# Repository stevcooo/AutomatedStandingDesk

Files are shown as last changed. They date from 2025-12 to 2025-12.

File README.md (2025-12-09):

Here is my story.
Like many of us who work from home, after a while, you start to think that a standing desk would be a nice addition to your home setup. And yes, it is, but it’s cool and nice only in the beginning, at least for me. Then I stopped using it, and it became a regular desk, which from time to time served as an expensive lift toy for my daughter… but it looks like she lost interest too.

Unfortunately, the model I got has controls to adjust the height (up and down) and four positions that can be memorized. You find a nice height that works for you, you memorize it, and if you move it up and down later, you can easily return to your desired state. Kind of like a digital radio system.

Turns out, not using your standing desk after a while is a common thing. I’ve checked with many of my friends and colleagues. Okay, let’s automate it. How hard can it be?

We need something that will press the button. We have two options here: you can buy a [Fingerbot](https://www.aliexpress.com/item/1005005923713363.html) for $40 and skip reading the whole saga below, or you can keep reading and spend a few days on it—it's more fun, I can guarantee.

If you’ve made it this far, I assume you’re either curious or you have some extra time to spend. Let’s go!

> _There is a links section in the end of the document where I listed links for each of the parts that I mention in the text_

A servo motor can do the trick, even the cheapest one. Someone needs to give the signal to the motor to start rotating, press the button, and then release it. Okay, any Arduino board will do the trick.

Next, you need to be able to set a time when you want your desk to move to a standing position. For that, you need something that will keep the date/time running and inform the Arduino. Turns out there are tons of components that can do that. I know, ChatGPT told me! I bought a cheap one, the `DS3231`. It can even be attached to a battery, so it won’t lose time if you unplug the power for some reason. Cool! Turns out the same component has an integrated alarm too, so you can set it as well. Perfect.

Imagine you put everything together. You still need a way to attach the motor to the desk controller, drilling or gluing it isn’t an option. After spending 30 minutes measuring and attempting four failed prints, my 3D printer finally managed to produce a perfect piece. Awesome!

[Check it out](https://github.com/stevcooo/AutomatedStandingDesk/blob/main/3DModel/MG50S_servo_mount_to_Strong_standing_desk_controller.stl)

Let’s bring everything together!
I’ve got an ESP32 with WiFi and a display, an MG90S micro servo motor, and a DS3231 for the clock. The good thing about the ESP32 with WiFi is that it can host a network where you can access the Arduino from your phone and set some values, like the date and time, and most importantly, the alarm for when you want the trigger to happen.

I won’t bore you with details here; the whole code is in the repository, where you can go through it or even edit it yourself to tweak it. I’m sure you can make this better!

All the wiring details and technical descriptions are below if you want to go deeper. You can also see the 3D design and edit it to fit your desk or motor.

Now, I set the alarm on the `DS3231` component via the Web interface and my desk is moving to standing position every day, 2minutes before the morning meeting. Yay!

Here is a video how it works in action (you may need to click on the picture to open the YouTube video):
<a href="https://www.youtube.com/watch?v=pzgJn2215ew" target="_blank">
Watch the video
</a>

# ESP32 Daily Alarm Clock + Servo Button Presser

An ESP32-based clock using a DS3231 RTC and SSD1306 OLED display.  
It hosts a Wi‑Fi Access Point with a small web UI to:

- Set date/time on the RTC
- Configure a **daily alarm**
- Disable the alarm
- View current RTC time

When the alarm fires, the DS3231 triggers an interrupt on the ESP32, and the ESP32 drives a servo that “presses a button” (or any physical switch) via a simple press‑and‑return routine.

---

## Features

- **Hardware timekeeping** via DS3231 RTC (battery‑backed)
- **OLED time display** updated once per second
- **Daily alarm** using DS3231 Alarm1 interrupt pin
- **Servo‑triggered action** on alarm
- **Wi‑Fi AP + Web UI** for easy setup without needing a router

---

## Pin Mapping (from the code)

These pins are defined in the sketch:

| Module / Signal | ESP32 Pin | Notes |
| --- | ---: | --- |
| **Servo signal** | GPIO **18** | `servoPin = 18` |
| **RTC Alarm INT/SQW** | GPIO **27** | `ALARM_INT_PIN = 27`, input pullup, falling edge ISR |
| **I2C SDA** | GPIO **21** | `Wire.begin(21,22)` |
| **I2C SCL** | GPIO **22** | `Wire.begin(21,22)` |
| **OLED I2C addr** | 0x3C | `OLED_ADDR = 0x3C` |
| **Wi‑Fi AP SSID** | `ESP32-Clock` | password `12345678` |

RTC and OLED **share the same I2C bus**.

---

## Wiring Table

### 1) DS3231 RTC

<p align="center" width="100%">
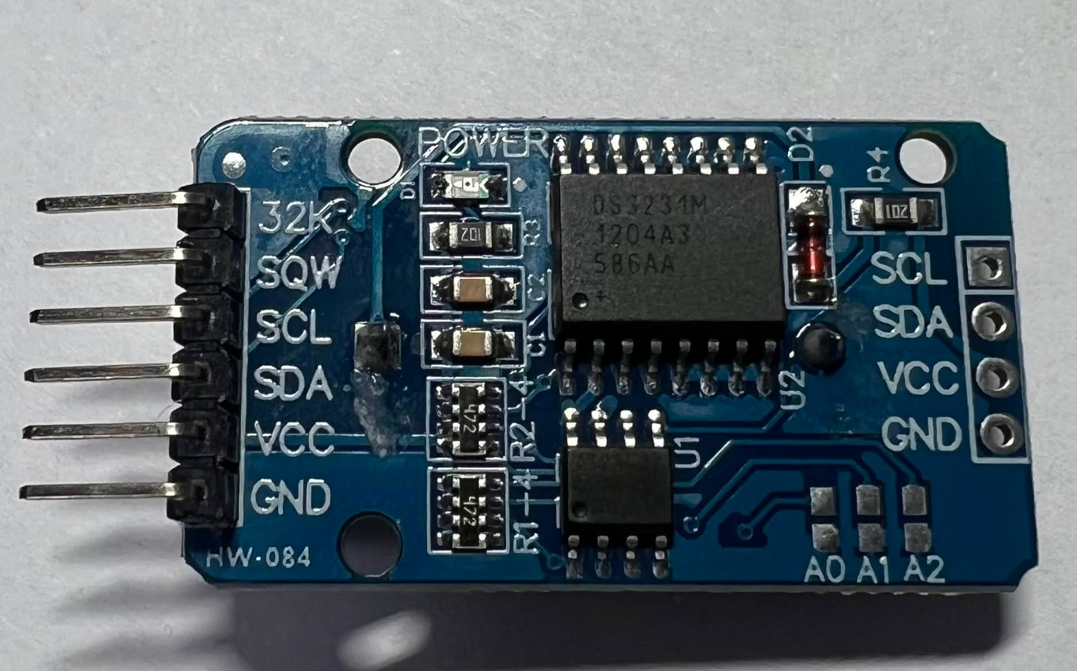
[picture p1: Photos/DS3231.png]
   
</p>

| DS3231 Pin | Connect to ESP32 | Notes |
| --- | --- | --- |
| VCC | 3V3 | DS3231 modules are usually 3.3–5V tolerant; 3V3 is safest |
| GND | GND | common ground |
| SDA | GPIO 21 | I2C data |
| SCL | GPIO 22 | I2C clock |
| INT/SQW | GPIO 27 | alarm interrupt output |

### 2) Servo (standard 3‑wire)

<p align="center" width="100%">
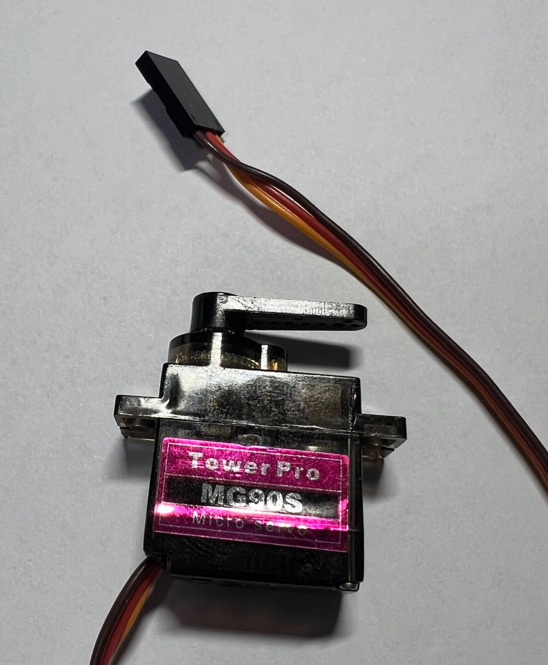
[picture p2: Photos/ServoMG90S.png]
   
</p>

| Servo Wire | Connect to ESP32 | Notes |
| --- | --- | --- |
| Signal (usually yellow/orange) | GPIO 18 | PWM via LEDC |
| V+ (usually red) | **5V external** recommended | ESP32 5V pin _might_ work for micro servos but can brown out |
| GND (usually brown/black) | GND | must share ground with ESP32 |

> Important: servo power spikes can reset the ESP32. Use a separate 5V supply if possible, and **tie grounds together**.

---

## Graphical Wiring Diagram (Fritzing‑style, text)

Legend:

- `==` I2C bus line (shared)
- `---` single signal line
- `+++` power rail
- `⏚` ground rail

```
                    ┌──────────────────────────────┐
                    │             ESP32            │
                    │                              │
   3V3  +++─────────┤ 3V3                      GND ├────────⏚
                    │                              │
   SDA  ==──────────┤ GPIO21 (SDA)                 │
   SCL  ==──────────┤ GPIO22 (SCL)                 │
 Alarm ---──────────┤ GPIO27                       │
 Servo ---──────────┤ GPIO18 (PWM)                 │
                    └──────────────┬───────────────┘
                                   │
                   ┌───────────────┼
                   │               │
                   │               │
        I2C BUS ===│=== SDA/SCL ===│
                   │               │
                   ▼               ▼

      ┌─────────────────┐   ┌─────────────────┐
      │    DS3231 RTC   │   │      SERVO      │
      │                 │   │                 │
      │ VCC  +++────────┼───│ V+   +++ 5V EXT │
      │ GND  ⏚──────────│───│ GND  ⏚───────── ┼───⏚
      │ SDA  ==─────────┼───│ SIG  --- GPIO18 │
      │ SCL  ==─────────┼───└─────────────────┘
      │ INT  --- GPIO27 │
      └─────────────────┘
```

Power rails:

- **3V3 rail** feeds **RTC VCC** and **OLED VCC**
- **5V external rail** feeds **Servo V+**
- **All grounds join at ESP32 GND**

---

## How It Works

1. **RTC time** is read once per second and drawn on the OLED.
2. **Daily alarm** is set using DS3231 Alarm1 in “match hour/min/sec” mode.
3. When alarm time matches, DS3231 pulls **INT/SQW low**, triggering ESP32 ISR.
4. Main loop sees `alarmFiredFlag` and:
   - clears RTC alarm flag
   - runs `pressAndReturn()` to actuate the servo

Servo routine (timings from code):

- Move “back” for `travelMs`
- Hold for `holdMs`
- Move “press” for `travelMs`
- Stop and settle

You can tune:

```cpp
int pressUs  = 1150;
int backUs   = 1890;
int travelMs = 60;
int holdMs   = 15000;
int settleMs = 200;
```

---

## Setup & Usage

### 1) Flash the ESP32

<p align="center" width="100%">
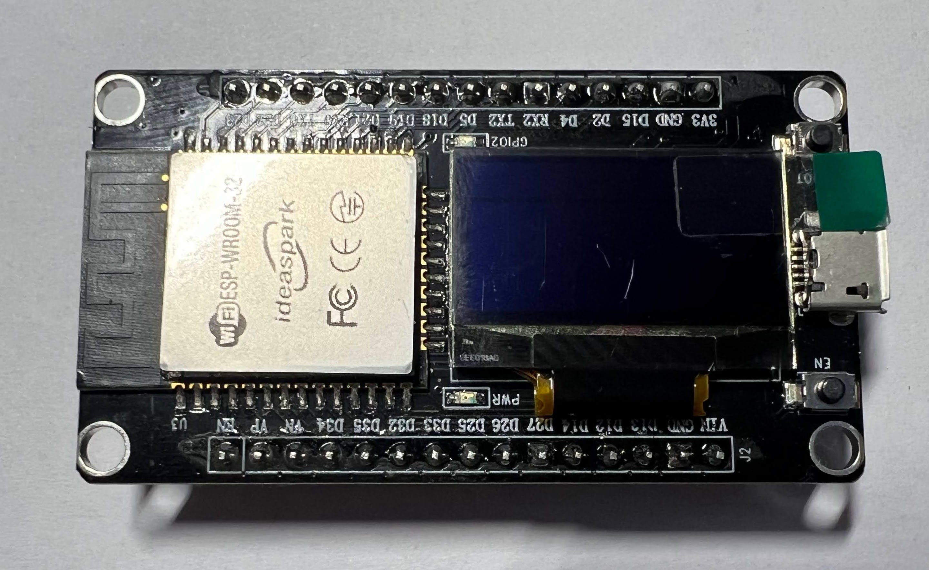
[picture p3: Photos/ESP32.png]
   
</p>

Open in Arduino IDE (ESP32 core installed), select your board, then upload.

Here is my configuration for the board:

<p align="center" width="100%">
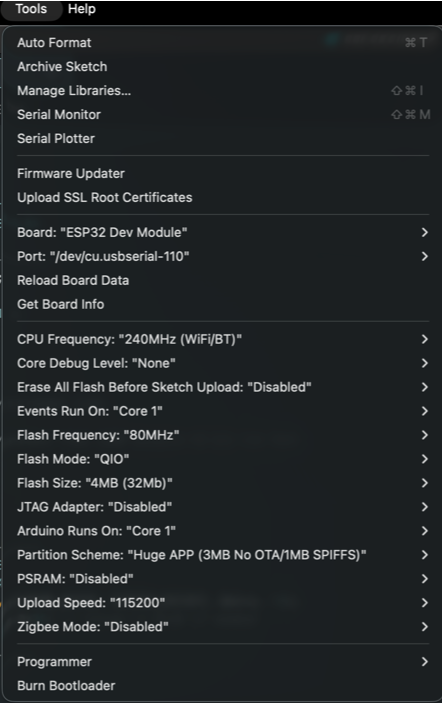
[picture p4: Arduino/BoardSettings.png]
   
</p>

### 2) Connect to AP

On your phone/laptop:

- SSID: **ESP32-Clock**
- Password: **12345678**

### 3) Open Web UI

Navigate to:

- `http://192.168.4.1/`

You’ll see:

- **Set Date & Time**
- **Daily Alarm**
- **Disable Alarm**
- **Status link**

<p align="center" width="100%">
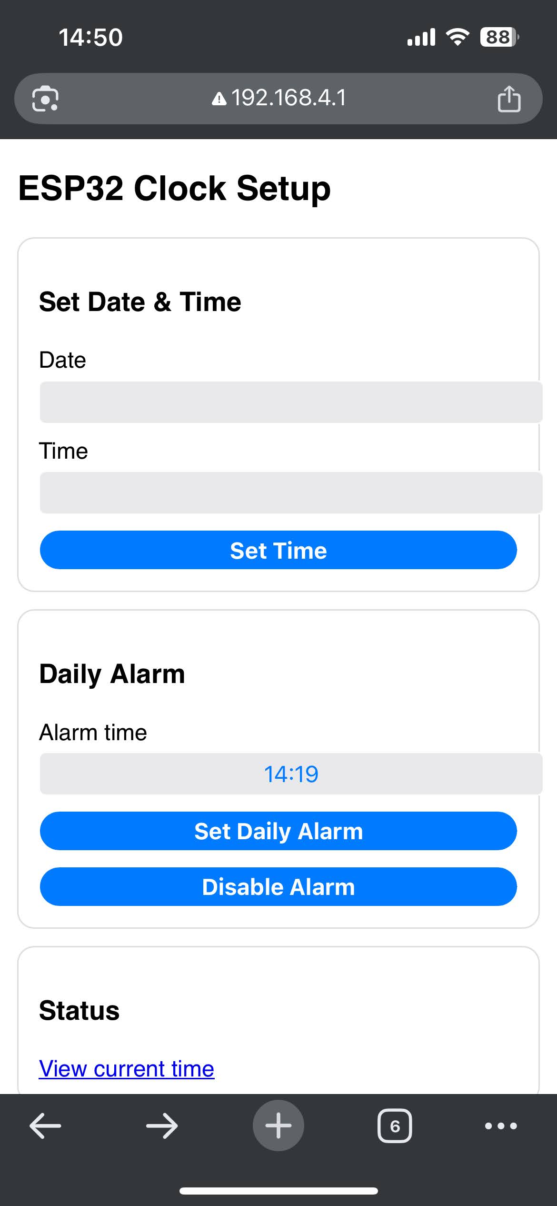
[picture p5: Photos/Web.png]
   
</p>

### 4) Status Endpoint

`http://192.168.4.1/status` returns plain text:

```
YYYY-MM-DD HH:MM:SS
```

---

## Notes / Tips

- If your OLED doesn’t show anything, your module may be at **0x3D**; change:
  ```cpp
  const uint8_t OLED_ADDR = 0x3D;
  ```
- DS3231 INT pin is **open‑drain active‑low**, so `INPUT_PULLUP` is correct.
- If the alarm fires immediately after setting:
  - you likely left a stale alarm flag; the code clears alarms on set and on fire.
- Use a proper 5V servo supply for reliability.

---

## Possible Extensions

- Add a “test servo” button to the UI
- Add multiple alarms (Alarm2 or software scheduling)
- Sync time from NTP when connected to the internet
- Show alarm status / next alarm time on OLED
- Draw PCB board where you can put the components directly, something like motherboard

## Links

- [3D model STL](/3DModel/MG50S_servo_mount_to_Strong_standing_desk_controller.stl)
- [3D model online](https://www.tinkercad.com/things/0ZuuW3NavJP-fantabulous-amur-lahdi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)
- [ESP32 Development Board with 0.96 Inch OLED Display](https://www.aliexpress.com/item/1005006269242344.html?spm=a2g0o.order_list.order_list_main.90.ea711802LYOdQG)
- [Micro Servo MG90S](https://www.aliexpress.com/item/32945021008.html)
- [DS3231](https://www.aliexpress.com/item/1005006996032750.html)
- [PCB Board Protoboard For Arduino](https://www.aliexpress.com/item/32981958921.html)

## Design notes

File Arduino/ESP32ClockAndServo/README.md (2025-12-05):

# ESP32 DS3231 Clock + OLED + Daily Alarm (Wi-Fi AP Web UI)

This project runs on an **ESP32** connected to a **DS3231 RTC** and a **128×64 SSD1306 OLED**.  
The ESP32 creates a Wi-Fi Access Point, hosts a small web UI, and lets you:

- Set **date & time** on the DS3231  
- Set a **daily alarm** (HH:MM or HH:MM:SS)  
- Display current time on an OLED  
- Trigger an interrupt when the alarm fires (for your custom action)

---

## Features

- **Self-hosted AP + Web UI** (no router required)  
- **RTC-backed timekeeping** (DS3231 battery keeps time when ESP32 is off)  
- **Daily repeating alarm** using DS3231 Alarm1 + INT pin  
- **OLED live clock** update every second  
- Alarm time parser accepts both `HH:MM` and `HH:MM:SS`

---

## Hardware

### Required
- ESP32 dev board
- DS3231 RTC module
- SSD1306 128×64 I2C OLED (0x3C typical)
- Jumper wires
- (Optional) DS3231 coin cell battery (CR2032)

---

## Wiring / Schematics

### I2C Bus Connections

Both the DS3231 and OLED share the same I2C bus:

| ESP32 Pin | DS3231 Pin | OLED Pin | Notes |
|---:|---|---|---|
| 3V3 | VCC | VCC | Use 3.3V unless your modules explicitly require 5V |
| GND | GND | GND | Common ground |
| GPIO21 | SDA | SDA | I2C data |
| GPIO22 | SCL | SCL | I2C clock |

### Alarm Interrupt Connection

| ESP32 Pin | DS3231 Pin | Notes |
|---:|---|---|
| GPIO27 | SQW / INT  | Alarm output, active LOW. ESP32 uses INPUT_PULLUP. |

### ASCII Schematic

```
                +------------------+
                |      ESP32       |
                |                  |
3V3  ---------- | 3V3          GND | ---------- GND
GND  ---------- | GND              |
SDA (GPIO21) -- | GPIO21 (SDA)     |
SCL (GPIO22) -- | GPIO22 (SCL)     |
INT (GPIO27) -- | GPIO27           |
                +------------------+
                     |   |   |
                     |   |   |
                     |   |   +-------------------+
                     |   |                       |
                     |   +-----------+           |
                     |               |           |
          +----------------+   +----------------------+
          |    DS3231      |   |   SSD1306 OLED       |
          |                |   |                      |
          | VCC   GND SDA  |   | VCC  GND  SDA  SCL   |
          |  |     |   |   |   |  |    |    |    |    |
          +--|-----|---|---+   +--|----|----|----|----+
             |     |   |          |    |    |    |
             |     |   +----------+    |    |    |
             |     +-------------------+    |    |
             +------------------------------+    |
                                    +------------+
```

**Notes**
- Most DS3231 + SSD1306 I2C modules work fine at 3.3V. If yours is 5V-only, use 5V VCC but ensure SDA/SCL have pullups compatible with ESP32 (usually still OK because modules use open-drain).  
- INT/SQW on DS3231 is **open-drain active-low**, so ESP32 internal pull-up is correct.

---

## How It Works

1. ESP32 boots and initializes I2C, OLED, and RTC.
2. It disables and clears any old alarms on the DS3231.
3. ESP32 starts a **Wi-Fi Access Point**:
   - SSID: `ESP32-Clock`
   - Password: `12345678`
4. A web server runs at port 80 with:
   - `/` a setup UI
   - `/setTime` to set RTC time
   - `/setAlarm` to set daily alarm
   - `/alarmOff` to disable alarm
   - `/status` to read current time
5. When Alarm1 fires, DS3231 pulls INT low → ESP32 interrupt sets a flag → loop clears alarm and runs your action.

---

## Web Endpoints

### Set Date & Time
**GET /setTime?d=YYYY-MM-DD&t=HH:MM:SS**

Example:
```
/setTime?d=2025-12-01&t=14:30:00
```

### Set Daily Alarm
**GET /setAlarm?a=HH:MM** or **HH:MM:SS**

Examples:
```
/setAlarm?a=07:00
/setAlarm?a=07:00:30
```

If seconds are missing, they default to `00`.

### Disable Alarm
**GET /alarmOff**

### Read Current Time
**GET /status**

Returns:
```
YYYY-MM-DD HH:MM:SS
```

---

## Finding the AP IP Address

When ESP32 creates the AP, it prints the IP to Serial:

```cpp
Serial.print("AP IP: ");
Serial.println(WiFi.softAPIP());
```

### Default IP
ESP32 SoftAP commonly uses:
```
192.168.4.1
```
…but you should **trust the Serial output**.

### If the IP doesn’t match / you can’t connect
1. **Open Serial Monitor** at `115200 baud`
2. Reset the ESP32
3. Look for:
   ```
   AP IP: x.x.x.x
   ```
4. Use that IP in your browser:
   ```
   http://x.x.x.x/
   ```

If you still can’t see the network:
- Ensure ESP32 is in AP mode (`WiFi.mode(WIFI_AP)`)
- Confirm SSID/password in code
- Try forgetting the network on your device and reconnecting

---

## Customizing Alarm Action

In `loop()`:

```cpp
if (alarmFiredFlag) {
  alarmFiredFlag = false;
  rtc.clearAlarm(1);
  // Alarm action here
  Serial.println("ALARM!");
}
```

Replace the comment with anything you want (servo, relay, buzzer, etc).

---

## Troubleshooting

### OLED does not display
- Check OLED I2C address (0x3C vs 0x3D).
- Use an I2C scanner if unsure.
- Confirm SDA/SCL wiring and shared ground.

### Alarm never fires
- Ensure SQW/INT pin is wired to GPIO27.
- Ensure `rtc.writeSqwPinMode(DS3231_OFF)` is called.
- Ensure you cleared old alarms before setting new ones.

### “Bad alarm format”
- Your browser might submit `HH:MM` only.  
  This project supports both `HH:MM` and `HH:MM:SS`.
- If you hit it manually, keep the correct format:
  ```
  /setAlarm?a=07:30
  ```

---

## Library Dependencies

Install via Arduino Library Manager:

- **RTClib** (Adafruit)
- **Adafruit SSD1306**
- **Adafruit GFX Library**
- **WiFi** (ESP32 core)
- **WebServer** (ESP32 core)

---

## License

MIT (or whatever you prefer)

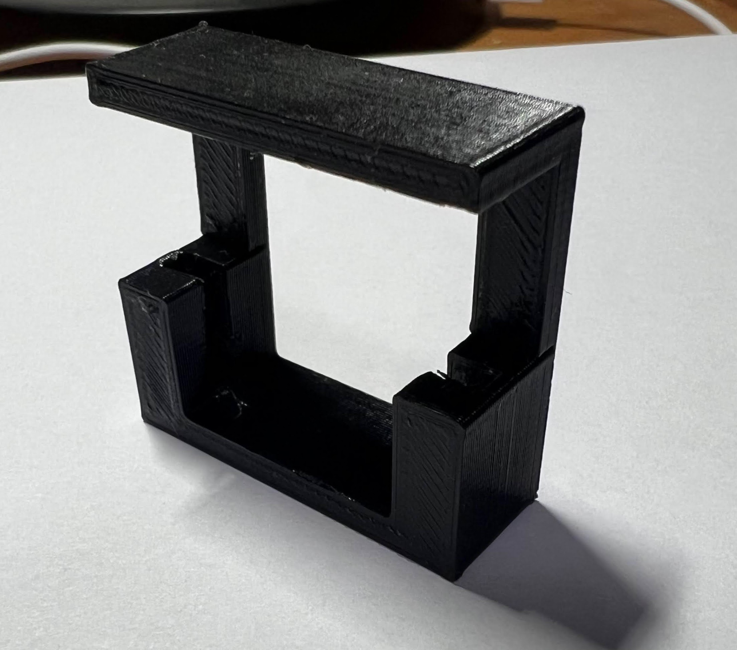
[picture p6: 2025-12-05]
Photos/3dModel2.png

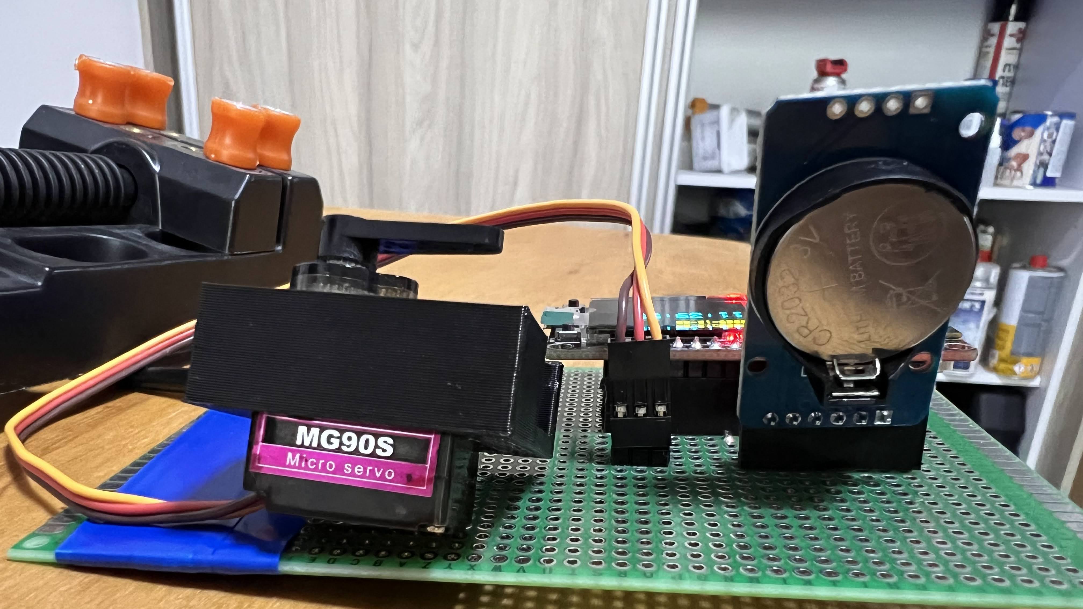
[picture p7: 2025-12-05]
Photos/BoardSide.png

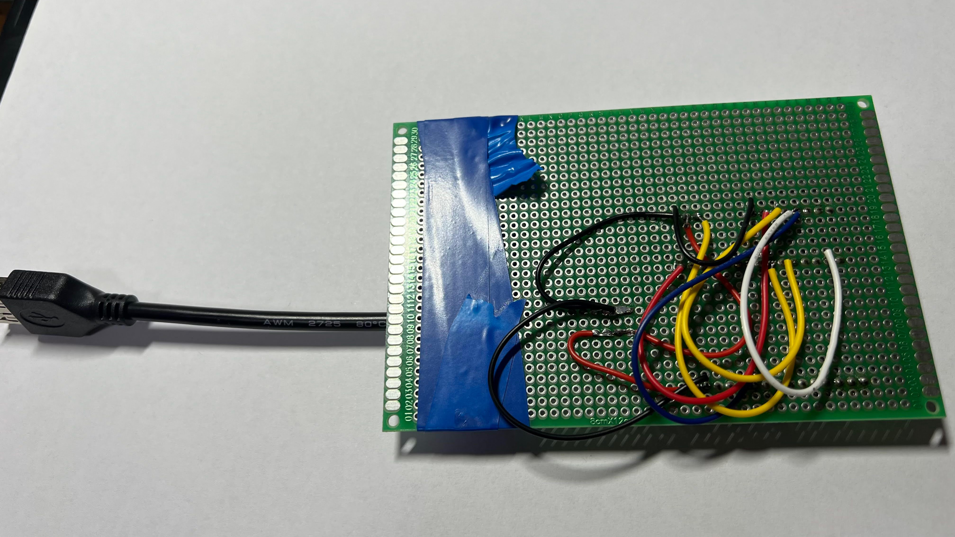
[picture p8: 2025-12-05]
Photos/BoardBack.png

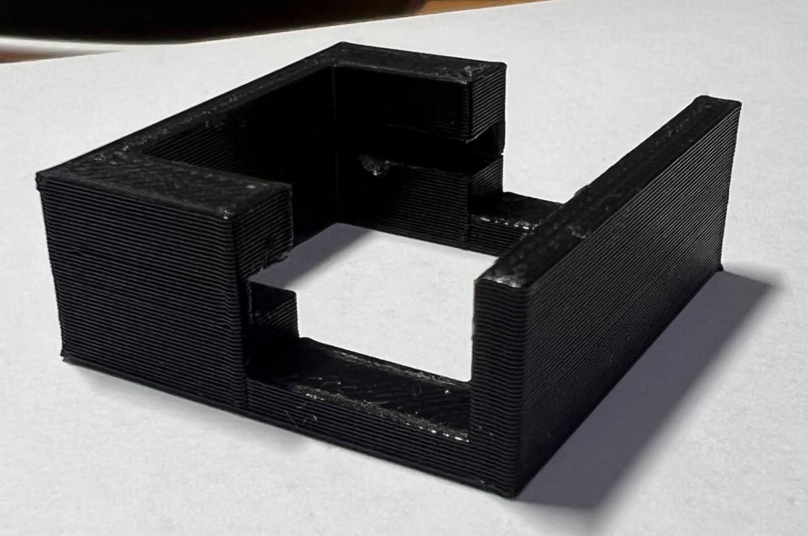
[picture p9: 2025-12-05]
Photos/3dModel1.png

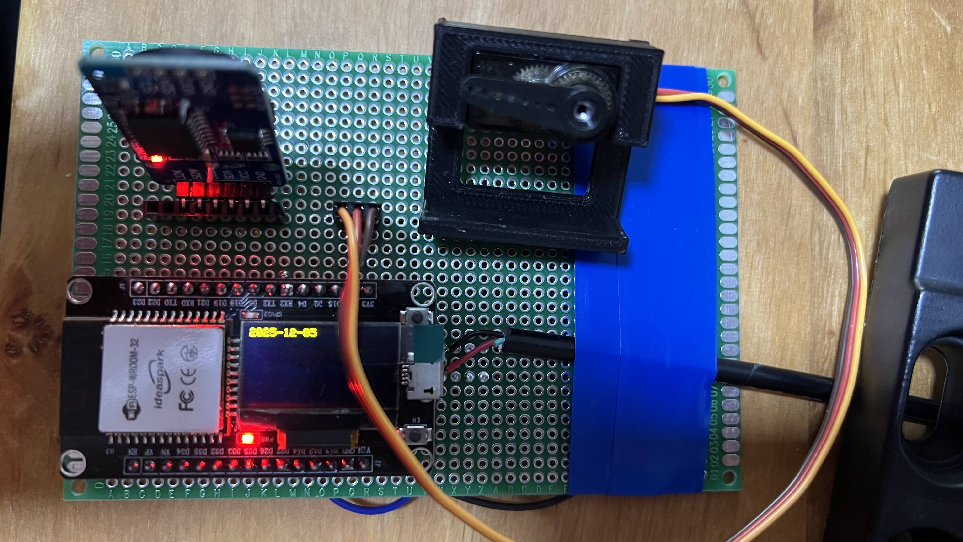
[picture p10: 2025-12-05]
Photos/BoardUP.png

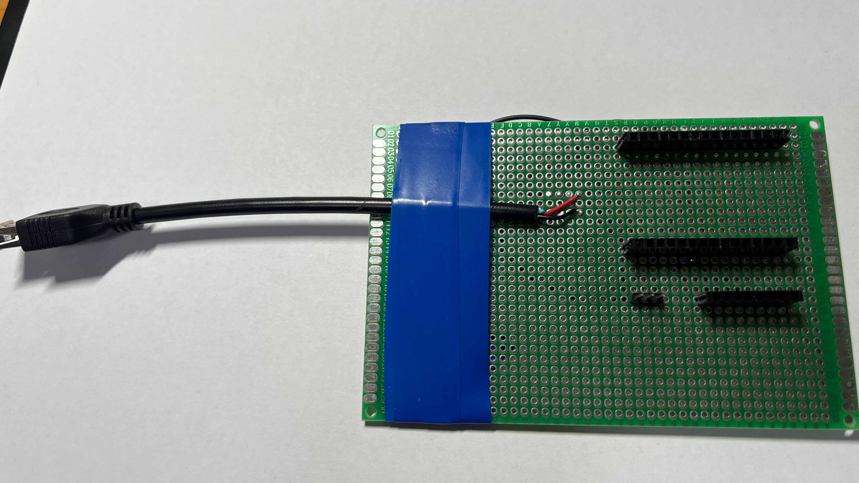
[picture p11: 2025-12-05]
Photos/BoardUpEmpty.png

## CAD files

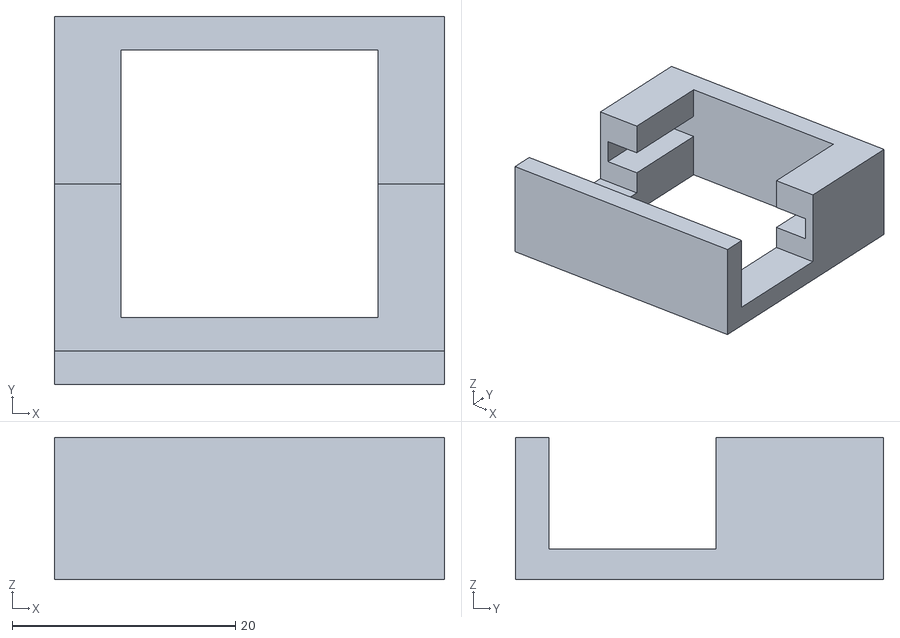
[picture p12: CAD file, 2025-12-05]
3DModel/MG50S_servo_mount_to_Strong_standing_desk_controller.stl
35.0 x 33.0 x 12.7

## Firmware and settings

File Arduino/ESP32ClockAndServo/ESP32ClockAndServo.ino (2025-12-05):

#include <Wire.h>
#include "RTClib.h"
#include <WiFi.h>
#include <WebServer.h>
#include <Adafruit_GFX.h>
#include <Adafruit_SSD1306.h>

// ---------- SERVO ----------
const int servoPin = 18;
const int freq = 50;
const int resolution = 16;

int stopUs = 1500;

// CCW (toward button)
int pressUs = 1150;   // stronger side
// CW (back)
int backUs  = 1890;   // weaker than 1900 because CW was too fast

int travelMs = 60;
int holdMs   = 15000;
int settleMs = 200;

// ---------- OLED ----------
#define SCREEN_WIDTH 128
#define SCREEN_HEIGHT 64
Adafruit_SSD1306 display(SCREEN_WIDTH, SCREEN_HEIGHT, &Wire, -1);
const uint8_t OLED_ADDR = 0x3C; // change to 0x3D if needed

// ---------- RTC ----------
RTC_DS3231 rtc;

// ---------- Wi-Fi AP + Web ----------
const char* ssid = "ESP32-Clock";
const char* pass = "12345678";
WebServer server(80);

// ---------- Alarm ----------
const int ALARM_INT_PIN = 27;          
volatile bool alarmFiredFlag = false;

void IRAM_ATTR onAlarmISR() {
  alarmFiredFlag = true;
}

void clearAndDisableAllAlarms() {
  rtc.disableAlarm(1);
  rtc.disableAlarm(2);
  rtc.clearAlarm(1);
  rtc.clearAlarm(2);
  rtc.writeSqwPinMode(DS3231_OFF);
}

void setDailyAlarm1(int h, int m, int s) {
  rtc.disableAlarm(1);
  rtc.clearAlarm(1);

  DateTime now = rtc.now();
  DateTime alarmTime(now.year(), now.month(), now.day(), h, m, s);

  // Fires when H:M:S match (once per day).
  rtc.setAlarm1(alarmTime, DS3231_A1_Hour);

  // Turn off square wave, enable INT mode for alarms
  rtc.writeSqwPinMode(DS3231_OFF);

  // Clear any stale flag
  rtc.clearAlarm(1);
}


void disableAlarm1() {
  rtc.disableAlarm(1);
  rtc.clearAlarm(1);
}

// ---------- OLED draw ----------
void drawTime(DateTime now) {
  display.clearDisplay();
  display.setTextColor(SSD1306_WHITE);

  display.setTextSize(1);
  display.setCursor(0,0);
  display.printf("%04d-%02d-%02d", now.year(), now.month(), now.day());

  display.setTextSize(2);
  display.setCursor(0,16);
  display.printf("%02d:%02d:%02d", now.hour(), now.minute(), now.second());

  display.display();
}

// ---------- Web UI ----------
String pageHtml() {
  return R"rawliteral(
<!doctype html>
<html>
<head>
  <meta name="viewport" content="width=device-width,initial-scale=1">
  <style>
    body{font-family:sans-serif;max-width:420px;margin:20px auto;padding:0 12px}
    h2{margin-top:0}
    .card{border:1px solid #ddd;border-radius:12px;padding:14px;margin:12px 0}
    label{display:block;margin:8px 0 4px}
    input{width:100%;font-size:16px;padding:8px}
    button{margin-top:10px;width:100%;padding:10px;font-size:16px}
  </style>
</head>
<body>
  <h2>ESP32 Clock Setup</h2>

  <div class="card">
    <h3>Set Date & Time</h3>
    <form action="/setTime">
      <label>Date</label>
      <input type="date" name="d" required>
      <label>Time</label>
      <input type="time" name="t" step="1" required>
      <button type="submit">Set Time</button>
    </form>
  </div>

  <div class="card">
    <h3>Daily Alarm</h3>
    <form action="/setAlarm">
      <label>Alarm time</label>
      <input type="time" name="a" step="1">
      <button type="submit">Set Daily Alarm</button>
    </form>
    <form action="/alarmOff">
      <button type="submit">Disable Alarm</button>
    </form>
  </div>

  <div class="card">
    <h3>Status</h3>
    <a href="/status">View current time</a>
  </div>
</body>
</html>
)rawliteral";
}

void handleRoot() {
  server.send(200, "text/html", pageHtml());
}

void handleStatus() {
  DateTime now = rtc.now();
  char buf[64];
  snprintf(buf, sizeof(buf),
           "%04d-%02d-%02d %02d:%02d:%02d",
           now.year(), now.month(), now.day(),
           now.hour(), now.minute(), now.second());
  server.send(200, "text/plain", buf);
}

void handleSetTime() {
  if (!server.hasArg("d") || !server.hasArg("t")) {
    server.send(400, "text/plain", "Missing date or time");
    return;
  }
  String d = server.arg("d"); // YYYY-MM-DD
  String t = server.arg("t"); // HH:MM:SS

  int Y,M,Dd,h,m,s;
  sscanf(d.c_str(), "%d-%d-%d", &Y,&M,&Dd);
  sscanf(t.c_str(), "%d:%d:%d", &h,&m,&s);

  rtc.adjust(DateTime(Y,M,Dd,h,m,s));
  server.send(200, "text/plain", "Time updated!");
}

void handleSetAlarm() {
  if (!server.hasArg("a") || server.arg("a").length() == 0) {
    server.send(400, "text/plain", "Missing alarm time");
    return;
  }

  String a = server.arg("a"); // might be HH:MM or HH:MM:SS
  int h=0, m=0, s=0;

  int n = sscanf(a.c_str(), "%d:%d:%d", &h, &m, &s);
  if (n < 2) {   // not even HH:MM
    server.send(400, "text/plain", "Bad alarm format (use HH:MM or HH:MM:SS)");
    return;
  }
  if (n == 2) s = 0; // default seconds if missing

  setDailyAlarm1(h, m, s);
  server.send(200, "text/plain", "Daily alarm set!");
}

void handleAlarmOff() {
  disableAlarm1();
  server.send(200, "text/plain", "Alarm disabled.");
}

int usToDuty(int us) {
  return (int)((us / 20000.0) * ((1 << resolution) - 1));
}

void writeUs(int us) {
  us = constrain(us, 500, 2500);
  ledcWrite(servoPin, usToDuty(us));
}

void setup() {
  Serial.begin(115200);
  Wire.begin(21,22);

  // Servo
  ledcAttach(servoPin, freq, resolution);
  writeUs(stopUs);

  if(!display.begin(SSD1306_SWITCHCAPVCC, OLED_ADDR)) {
    while(1);
  }

  if (!rtc.begin()) {
    while(1);
  }

  clearAndDisableAllAlarms();

  pinMode(ALARM_INT_PIN, INPUT_PULLUP);
  attachInterrupt(digitalPinToInterrupt(ALARM_INT_PIN), onAlarmISR, FALLING);

  if (rtc.lostPower()) {
    rtc.adjust(DateTime(F(__DATE__), F(__TIME__)));
  }

  WiFi.mode(WIFI_AP);
  WiFi.softAP(ssid, pass);
  Serial.print("AP IP: ");
  Serial.println(WiFi.softAPIP());

  server.on("/", handleRoot);
  server.on("/status", handleStatus);
  server.on("/setTime", handleSetTime);
  server.on("/setAlarm", handleSetAlarm);
  server.on("/alarmOff", handleAlarmOff);
  server.begin();
}


void pressAndReturn() {
  writeUs(backUs);
  delay(travelMs);
  
  writeUs(stopUs);
  delay(holdMs);

  writeUs(pressUs);
  delay(travelMs);

  writeUs(stopUs);
  delay(settleMs);
}

void loop() {
  server.handleClient();

  static unsigned long last = 0;
  if (millis() - last >= 1000) {
    last = millis();
    drawTime(rtc.now());
  }

  if (alarmFiredFlag) {
    alarmFiredFlag = false;
    rtc.clearAlarm(1);
    // Alarm action here
    Serial.println("ALARM!");
    pressAndReturn();
  }
}
